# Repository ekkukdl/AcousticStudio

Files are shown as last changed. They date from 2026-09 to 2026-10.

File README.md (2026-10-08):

# Acoustic Control Studio

2026-10-08 T6 단면 클릭·드래그, 선택/전체 제어점 XYZ 이동, 비동기 궤적 이송과 최신 프레임 큐를 추가했습니다.
`구성 → 제어점`에서 이동 대상·단면·간격을 선택하며, 느린 계산에서는 이전 waypoint를 완료한 뒤 진행합니다.
[사용법·검증·현재 PC 성능](docs/ultraino_t6_result.md)을 확인하세요. 실제 터널 부양·이송 검증은 남아 있습니다.

현재 개발 저장소는 **[ekkukdl/AcousticStudio](https://github.com/ekkukdl/AcousticStudio)** 하나로 통합했습니다. 2026-10-07 기준 `AcousticStudio_ver2`의 코드, 구상도·PCB·Creo 자료 및 로컬 수정 내용을 반영했으며 두 저장소의 커밋 이력을 보존했습니다.

화면은 **보기 → UI → 클래식 / 모던**에서 선택합니다. 두 화면 모두 상단 **보드** 메뉴를 사용합니다. 설계 자료는 [구상도 시작 안내](구상도/START_HERE.md), 최신 32채널 PCB는 [제작 자료 안내](구상도/outputs/panel_8faces_32ch_R1/README.md)를 참고하세요. 통합 범위와 검증 기록은 [저장소 통합 기록](docs/repository_consolidation.md)에 있습니다.

Ultraino 기능 이식은 [작업 계획](docs/ultraino_migration_plan.md)을 기준으로 진행합니다. 현재 대상은 **Creo R2의 8면·8기판·기판당 32송신기, 총 256채널**이며 터널 축은 Z입니다. 기존 배열 좌표와 개발 환경을 재사용하는 범위 및 단계별 완료 조건을 정리했습니다. [입력·환경 점검 결과](docs/ultraino_migration_audit.json)는 현재 로컬 설치 상태의 기록입니다.

Acoustic Control Studio는 초음파 부상(Ultrasonic Levitation) 및 역장 제어(Acoustic Field Control) 연구를 위한 **통합 3D 시뮬레이션 및 하드웨어 제어 소프트웨어**입니다.
이 프로그램은 사용자가 직관적인 3D UI를 통해 센서 배열을 설계하고, 타겟의 위치를 조작하며, 실시간으로 위상(Phase)을 계산하여 하드웨어 보드(아두이노, FPGA 등)로 직접 전송할 수 있는 All-in-One 플랫폼을 제공합니다.

---

## 주요 기능 (Features)
- **3D 대화형 인터페이스 (Interactive 3D UI)**: PyVista 및 PySide6를 기반으로 한 3D 뷰어 제공.
- **다양한 배열 생성**: 터널형, 평면형, 반구형 등 복잡한 센서 배열(Array) 자동 생성 지원.
- **이기종 센서 하이브리드 지원**: 일반 10mm/16mm 초음파 센서와 고출력 랑주뱅(Langevin) 진동자의 혼합 시뮬레이션 지원.
- **실시간 위상 연산 (Real-time Phase Calculation)**: Twin Trap, Vortex Trap 등의 알고리즘을 적용하여 타겟 이동 시 위상을 즉각 재계산하고 색상으로 시각화.
- **하드웨어 연동 (USB Serial)**: 계산된 위상 데이터를 Byte 형식으로 변환하여 실시간으로 외부 제어 보드로 전송.

---

## 사전 설정 및 설치 가이드 (Prerequisites & Installation)

Creo 배열은 `구성 → 배열 형태 → Creo 8면 터널 · 8기판 × 32채널`을 선택하고 `배열 3D 렌더링 생성`으로 추가합니다. 기존 CAD 좌표를 읽으므로 일반 Grid/Spacing 값은 적용되지 않습니다. 위치·회전은 배열 전체에 적용되며, PCB 8개와 프레임 링 2개는 간략 형상으로 표시합니다. [구현 및 검증 기록](docs/ultraino_t1_result.md)을 참고하세요.

`음장 → 공통 음향 모델`에서 무지향, Ultraino sinc, 원형 피스톤을 선택합니다. 기본 개구는 미확정이며 CAD 외경에서 추정하지 않습니다. 방향성 모델에는 유효 음향 개구 반경이 필요하고, 음압은 미보정 상대값입니다. 설정을 바꾼 뒤 위상을 다시 계산하세요. [T2 결과 및 다음 작업](docs/ultraino_t2_result.md)에 데이터 계약과 검증 범위를 정리했습니다.

위상을 계산한 뒤 `음장 → 고정 위상 방사력·복원성 분석`에서 입자 물성, 중력, 평가 범위와 미분 간격을 입력합니다. 현재 송신을 고정한 XYZ 힘·퍼텐셜·복원 곡선과 전체 3×3 복원행렬을 확인하고 분석 JSON을 저장할 수 있습니다. 기본 물성은 예시이며 음압 미보정 상태의 힘은 N* 가정값입니다. 실제 중력 평형·부양 판정은 보류합니다. [T3 결과](docs/ultraino_t3_result.md)를 참고하세요.

다중 제어점을 활성화하고 `음장 → 다중 트랩 설계 (Kinoforms)`를 엽니다. 각 점에 Focus/Twin/Standing Wave, 상대 목표 음압 가중치와 세계 좌표 방향을 지정해 함께 계산합니다. 송신기 이득은 고정하고 위상만 조절하며, 반복 잔차·가중 음압 균일도를 확인한 뒤 `선택 트랩의 고정 위상 분석`으로 T3 복원 부호를 검사할 수 있습니다. `현재 배열에 위상 적용`과 `설계 JSON 저장`을 지원합니다. 음압 균일도는 부양 성공률이 아닙니다. [T4 사용·검증 및 T5 인계](docs/ultraino_t4_result.md)에 재현 방법을 정리했습니다.

`보드 → 채널 보정·맵 및 OFF 프레임…`에서 SW 채널별 위상 오프셋·고정 상대 이득·활성 상태와 후보 채널 맵을 편집하고 JSON/프로젝트로 저장합니다. 보정·맵·양자화·OFF는 실시간 송신과 궤적 내보내기에서 공통 사용합니다. 지원 프로파일의 OFF32와 위상0을 구분하며 Legacy OFF는 거절합니다. 실제 COM 없이 1채널/전체 OFF 프레임을 파일로 확인할 수 있습니다. [T5 사용·검증·T6 인계](docs/ultraino_t5_result.md)를 참고하세요. 실제 펌웨어·배선·파형 검증과 절대 음압 보정은 남아 있습니다.

상단 연산 모드에서 `PyTorch/CUDA: 선택 시 준비`를 선택하면 필요한 CUDA 패키지를 다운로드·확인한 뒤 그 모드를 적용합니다. `도구 → 라이브러리 관리자`의 `PyTorch/CUDA 사용` 체크도 같은 흐름입니다. 첫 준비는 수 GB 다운로드가 필요하며 이후 선택은 바로 전환합니다. 취소·실패는 이전 모드를 유지합니다. [선택 항목 적용 안내](docs/cuda_optional_selection.md)를 참고하세요. 다중 트랩은 복소 행렬 곱만 선택 엔진을 사용하며 작은 문제의 GPU 계산은 복사 비용 때문에 CPU보다 느릴 수 있습니다. [기존 원인·측정 기록](docs/multitrap_cuda_diagnosis.md)을 함께 확인할 수 있습니다.

현재 로컬 개발 환경은 Python 3.13.9이며, 확인한 인터프리터와 의존성은 [이식 계획의 환경 안내](docs/ultraino_migration_plan.md)에 있습니다. 기존 환경을 먼저 확인하고 재사용하세요. 기본 `py`가 선택하는 Python과 앱용 환경은 다를 수 있습니다. 필수 의존성 10개는 `requirements.txt`와 공통 설치 카탈로그에 일치하며, 확인한 버전은 [requirements-tested.txt](requirements-tested.txt)에 기록했습니다. T2는 이미 설치된 SciPy를 재사용했습니다. 아래 신규 설치 예시는 새 머신에 필요한 경우에 사용합니다.

### 1. Python 가상 환경 설정 (선택 사항이나 권장)
```bash
python -m venv venv
# Windows
venv\Scripts\activate
# Mac/Linux
source venv/bin/activate
```

### 2. 필수 라이브러리 설치
프로젝트 루트 폴더에 포함된 `requirements.txt`를 사용하여 의존성 패키지를 한 번에 설치합니다.
```bash
pip install -r requirements.txt
```
**[설치되는 주요 패키지]**
- `PySide6`: GUI 프레임워크
- `pyvista`, `pyvistaqt`, `vtk`: 3D 렌더링 및 기하학 연산 엔진
- `numpy`: 고속 배열 및 위상 수학 연산
- `pyserial`: 하드웨어(USB) 시리얼 통신 모듈

### 3. 프로그램 실행
모든 설치가 완료되었다면, 최상단 경로에서 아래 명령어를 통해 메인 창을 띄울 수 있습니다.
```bash
python main.py
```

---

## 디렉터리 구조 (Directory Structure)
- `src/acousticstudio/`: 애플리케이션의 핵심 소스 코드 (`app.py`, `app_backup.py` 등)
- `main.py`: 프로그램 실행 진입점 (Entry point)
- `docs/`: AI 에이전트 가이드라인 및 프로젝트 진행 상태(`project_status.txt`)가 기록된 문서 폴더
- `archive/temp_scripts/`: 개발 과정에서 생성된 임시 수정 스크립트(수동 코드 인젝션 파일) 모음 보관소
- `requirements.txt`: 의존성 패키지 목록

---

## 주의 사항 (Notes)
- **그래픽 드라이버**: 3D 렌더링 엔진인 VTK/PyVista를 사용하므로, 그래픽 드라이버(OpenGL 호환)가 정상적으로 설치된 환경에서 실행해야 튕김 현상이 발생하지 않습니다.
- **AI 작업 지침**: GPT/Codex를 포함한 코딩 에이전트는 [AGENTS.md](AGENTS.md)의 작업·백업·검증 규칙을 따릅니다. 기존 `GEMINI.md`도 이 공통 지침을 안내합니다. 스킬 점검 내역은 [docs/skill_audit.md](docs/skill_audit.md)에 있습니다.

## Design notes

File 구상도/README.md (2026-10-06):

# 부양 터널 구상도와 제작 자료

**현재 파일 위치와 최신 작업 안내는 [시작 안내](START_HERE.md)를 기준으로 찾으세요.** 아래 이동 기록은 2026-10-05 당시의 폴더 구조입니다. 2026-10-06 정리 후 PCB 자료는 `outputs/pcb/polygon_panels`, 모델 생성 기록은 `outputs/cad_generation`에 있습니다. 이전 경로와 실행 안내는 과거 기록으로 보존합니다.

기존 모델 폴더와 함께 설계 산출물 및 작업 스크립트를 이 폴더에서 관리합니다.

## 최신 제작분: 면당 32채널 PCB와 프레임

- [KiCad 10 회로도·PCB·제작 자료](outputs/panel_8faces_32ch_R1/README.md): 한 면에 4×8개, 8면 총 256채널. PCB 84×224×1.6 mm, 발진면 간격 210 mm.
- [진녹색 PCB 및 외부 프레임 Creo R2](outputs/panel_8faces_32ch_R1/mechanical/creo32_frame_R2/사용안내.md): 상하 팔각 링 2개, 외형 265×265×224 mm, 면 사이 촬영용 틈 유지.
- [프레임 포함 모델 ZIP](outputs/panel_8faces_32ch_R1/mechanical/creo32_frame_R2/Creo32_frame_R2_models.zip), [전체 제작 자료 ZIP](outputs/panel_8faces_32ch_R1/Design_R1_complete.zip).
- [기존 회로·제작 방식 분석](outputs/pcb_review_2026-10-06/), [KiCad 스킬 설치 기록](outputs/KiCad10_스킬_설치기록.md).

이전 16장 구성은 아래 폴더에 보존했습니다. 최신 설계의 검사 범위와 미확정 사항은 각 사용안내·검토 문서에 기록했습니다. `scratch/creo32_env` 등 실행 환경, PTC 설치 파일, Creo 실행 로그 및 KiCad 로컬 UI 설정은 Git에 포함하지 않습니다. Creo 세션의 PTC 런타임은 설치된 Creo에서 `prepare_creo32_r1.py`로 복사하며, 새 컴퓨터에서는 경로와 실행 환경을 맞춰야 합니다. 최상위 `제개설/8면_256채널_PCB_프레임_2026-10-06` 폴더는 로컬 정리본이며 이 저장소의 최신 산출물을 복사한 것입니다.

- `creo_tunnel/`: 정리된 Creo 모델. 단일 패널 초기안과 면당 두 패널의 최신안을 구분합니다.
- `outputs/`: KiCad 설계, Gerber 견적 ZIP, BOM·PnP, 개념 모델, 분석 결과, 원본 업체 템플릿.
- `scratch/`: 모델 생성·검증·견적 파일 생성 스크립트 및 중간 결과.
- `outputs/polygon_panels/pcba_8faces_16boards/DOILLABS/`: 최신 DOILLABS 양식의 BOM·PnP XLSX. 8면, 면당 두 기판, 총 16장 구성입니다.

이전 상위 자료조사 폴더의 `outputs/`와 `scratch/`는 2026-10-05에 이 위치로 이동했습니다. 내부 상대 디렉터리 구조와 파일 내용은 유지했습니다. 이동 전후 SHA-256 비교 기록은 `artifact_move_verification.json`에 있습니다.

`scratch/creo_cad_env/` 가상환경과 `scratch/pcba_artifact/node_modules/` 외부 라이브러리 연결은 로컬에 보존하며 Git에는 포함하지 않습니다. 다른 컴퓨터에서는 실행 환경을 별도로 준비해야 합니다. Windows 가상환경은 경로가 이동되면 실행기 내부 경로가 이전 위치를 가리킬 수 있으므로 필요 시 새 위치에서 재구성합니다.

상대 `outputs/`와 `scratch/` 경로를 사용하는 스크립트는 이 `구상도` 폴더를 작업 디렉터리로 사용합니다. 기존 스크립트에 남은 절대 경로, 이전 실행 기록의 경로, 일부 스크립트의 `AcousticStudio/` 참조는 생성 당시 기록입니다. 실행 전 해당 경로를 점검해야 합니다. 이번 작업은 파일 이동과 내용 보존을 검증했으며 Creo 재실행이나 전체 생성 스크립트의 재실행은 수행하지 않았습니다.

PCB 파일은 견적용 P0 설계입니다. 업체의 간격 경고, 부품 품번 및 실장 방향 확인은 아직 제조 승인 전에 필요합니다. 부양 성능은 실물 시험으로 검증해야 합니다.

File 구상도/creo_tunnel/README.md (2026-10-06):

# 초음파 부양 터널 Creo 모델

이 폴더는 이전 16채널 기판의 모델입니다. 현재 기준은 **8면·8기판·기판당 32송신기**인 [Creo R2 사용안내](../outputs/panel_8faces_32ch_R1/mechanical/creo32_frame_R2/사용안내.md)의 `tunnel8_32_r2.asm`입니다. 아래 v2의 16기판 모델을 현재 소프트웨어 배열 입력으로 사용하지 마세요.

Creo Parametric 9.0.12.0에서 저장한 모델입니다. 길이 단위는 mm(mmNs)입니다.

## 이전 v2 모델 열기

Creo 작업 폴더를 **`v2_dual_panel/native`**로 지정한 뒤 다음 조립품을 엽니다. ASM과 참조 PRT는 같은 폴더에 함께 보관해야 합니다.

- [8면 · 각 면에 PCB 두 장](v2_dual_panel/native/tunnel_8f_dual.asm)
- [6면 · 공통 패널 참조 구조](v2_dual_panel/native/tunnel_6f_v2.asm)
- [한 면의 PCB 두 장과 촬영 틈](v2_dual_panel/native/facepair_8f.asm)
- [이전 v2 모델 사용 안내](v2_dual_panel/사용안내.md)

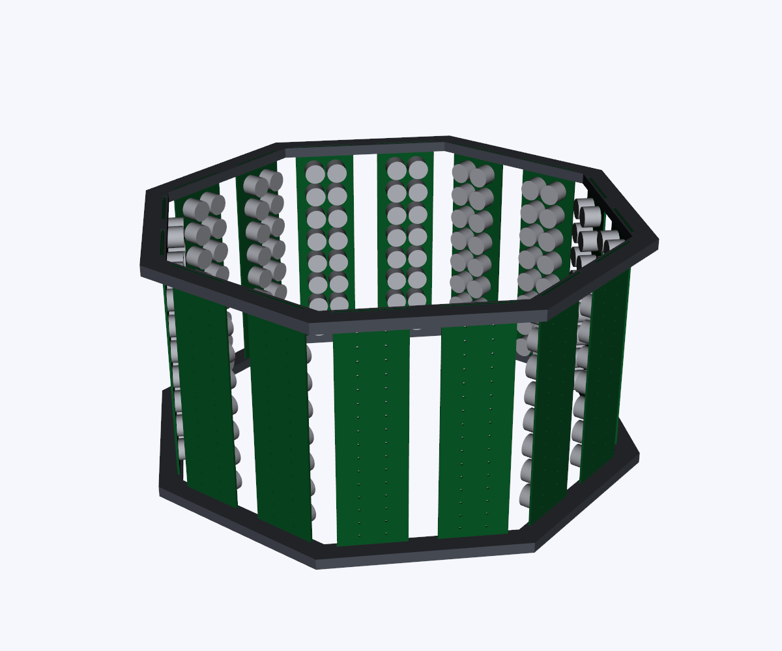
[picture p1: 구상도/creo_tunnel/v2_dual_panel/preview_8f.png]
이전 8면 v2 모델


## 버전 구분

| 폴더 | 6면 | 8면 |
|---|---|---|
| `v1_single_panel` | 면당 PCB 1장, 총 6장·96개 | 면당 PCB 1장, 총 8장·128개 |
| `v2_dual_panel` | 치수 유지, 공통 패널 ASM 재사용 | 면당 PCB 2장, 총 16장·256개, 중앙 촬영 틈 20 mm |

이전 6면 PCB는 60×180×1.6 mm, 8면 PCB는 48×180×1.6 mm입니다. 이전 v2의 8면은 각 면이 45° 간격인 정팔각형 배치이며, 마주 보는 방사면 간 거리는 300 mm, 전체 외곽은 약 355×355×180 mm입니다. 이전 두 조립품이 공유하는 네이티브 파일 종류는 총 10개입니다.

이전 v2의 8면은 `facepair_8f.asm` 하나를 8번 참조하고, 각 면은 `panel_8f.asm` 하나를 두 번 참조합니다. 동일한 PCB, 트랜스듀서 및 프레임 링도 공통 PRT를 참조합니다.

## 함께 보관한 자료

- `native`: 실제 Creo PRT/ASM. 재저장 시 붙는 `.1`, `.2` 등은 Creo 버전 번호입니다.
- `geometry`: 이전 v2 모델의 STEP 형상 및 배치·간섭 검사 기록.
- `pcb_geometry.json`: 기존 KiCad PCB에서 추출한 외곽 치수, 관통 구멍 및 트랜스듀서 좌표.
- `native_*report.json`: Creo 저장 및 새 세션에서 다시 열어 확인한 기록.
- `preview_*.png`: STEP 형상을 렌더링한 미리보기이며 Creo 화면 캡처는 아닙니다.
- `manifest.json`: 이 폴더에 정리된 파일의 SHA-256과 크기.

초기 모델의 STEP과 미리보기는 각 `6faces`, `8faces` 폴더에 있습니다. 기존 `구상도/ver1`~`ver4`는 별도의 기존 사용자 모델입니다.

## 검증 범위

원본과 정리된 파일의 SHA-256 일치, 네이티브 참조 파일의 완비 및 mm 치수 정보를 확인했습니다. 이전 v2 모델은 생성 당시 Creo 9에서 다시 열어 치수·반복 참조·배치 행렬·Fix 구속을 확인했고, 포함된 솔리드의 체적 간섭 검사도 수행했습니다.

PCB와 트랜스듀서는 가져온 솔리드이므로 스케치·돌출 피처 이력은 없습니다. 나사·브래킷·전자 부품·핀·배선은 생략되어 있습니다. 촬영 성능과 실제 부양 성능은 아직 검증하지 않았습니다.

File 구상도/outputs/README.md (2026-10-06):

# 결과물 안내

| 폴더 | 내용 |
|---|---|
| [pcb](pcb/README.md) | PCB 원본, Gerber·BOM·PnP, 초기 견적 |
| [cad_generation](cad_generation/) | 모델 생성 기록과 기존 배포 ZIP. 편집용 모델은 `../creo_tunnel`에 있습니다. |
| [budgets](budgets/) | 예산 계산 결과 |
| [vendor_templates](vendor_templates/) | DOILLABS 원본 양식 |
| [reference_analysis](reference_analysis/) | SonicSurface 참고 설계 분석 |
| [concepts](concepts/) | 초기 터널 개념도 |
| [docs](docs/) | KiCad 도구 설치 기록 |

전체 안내는 [START_HERE](../START_HERE.md)를 참고하세요.

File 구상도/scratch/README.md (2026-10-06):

# 작업 스크립트와 임시 자료

| 폴더 | 용도 |
|---|---|
| [creo_scripts](creo_scripts/) | 형상 추출, Creo 변환·패키지 생성·검증 |
| [pcba_scripts](pcba_scripts/) | 부품 입력 추출 및 업체 요청 패키지 생성·검증 |
| [pcba_inputs](pcba_inputs/) | PCBA 생성용 JSON·CSV 입력 |
| [pcba_artifact](pcba_artifact/) | Node 표 생성 스크립트, 미리보기와 로컬 의존성 |
| [vendor_research](vendor_research/) | 업체 조사 자료와 다운로드한 JS |
| [organization](organization/) | 이번 정리 스크립트와 이동 검증 기록 |
| [organization/history](organization/history/) | 이전 이동·복사·확인 스크립트 보존 |
| `creo_cad_env` | 로컬 Python 환경. 기존 경로 유지, Git 제외 |

실행 시 작업 디렉터리는 **상위 `구상도`**입니다. 예: `python scratch/pcba_scripts/extract_pcba_parts.py`.

생성 스크립트는 결과물을 덮어쓸 수 있고 Creo 자동화는 로컬 Creo와 생성 당시 임시 파일이 필요합니다. 이번 작업은 Python 문법과 경로 확인만 수행했으며 생성 파이프라인 전체를 재실행하지 않았습니다. `organization/history`는 과거 배치 기준의 기록으로 재실행용이 아닙니다. `reorganize_files.py`도 일회성 이동 기록이므로 다시 실행하지 마세요.

업체 제출 파일은 [PCB 안내](../outputs/pcb/README.md)에서 찾으세요. `vendor_research`의 JS는 참고 자료이며 앱 코드가 아닙니다.

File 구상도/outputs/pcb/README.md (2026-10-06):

# PCB 설계 및 업체 제출 자료

## 현재 8면 8기판 32채널 구성

현재 개발 기준은 한 기판 32채널, 같은 기판 8장, 총 256송신기입니다. [32채널 PCB R1 제작 자료](../panel_8faces_32ch_R1/README.md)와 [프레임 포함 Creo R2](../panel_8faces_32ch_R1/mechanical/creo32_frame_R2/사용안내.md)를 사용하세요. 아래 16채널 기판 16장의 업체 제출 자료는 이전 구성으로 보존한 것입니다.

## 이전 8면 16기판 요청

한 기판 16채널, 동일 기판 총 16장, 송신기 총 256개 구성입니다.

- [전체 납땜 요청 안내](polygon_panels/pcba_8faces_16boards/README_업로드_및_납땜요청.md)
- [DOILLABS 업로드 사용 안내](polygon_panels/pcba_8faces_16boards/DOILLABS/사용안내.txt)
- [업로드 BOM CSV](polygon_panels/pcba_8faces_16boards/DOILLABS/DOILLABS_BOM_8faces_16ch_UPLOAD.csv)
- [업로드 PnP CSV](polygon_panels/pcba_8faces_16boards/DOILLABS/DOILLABS_PnP_8faces_16ch_UPLOAD.csv)
- [업로드 BOM XLSX](polygon_panels/pcba_8faces_16boards/DOILLABS/DOILLABS_BOM_8faces_16ch_UPLOAD.xlsx)
- [업로드 PnP XLSX](polygon_panels/pcba_8faces_16boards/DOILLABS/DOILLABS_PnP_8faces_16ch_UPLOAD.xlsx)
- [8면용 Gerber ZIP](polygon_panels/pcba_8faces_16boards/panel_8faces_16ch_Gerber_P0_quote.zip)

DOILLABS에는 안내에 따라 `*_UPLOAD` 파일을 사용하세요. CSV와 같은 내용의 XLSX를 중복 제출하지 마세요. 접미사 없는 기존 XLSX와 기존 견적 ZIP은 이전 작성본으로 보존했으며 최신 UPLOAD 파일을 포함한다고 간주하지 마세요. 초음파 송신기 등 THT는 별도 수삽 작업으로 요청해야 합니다.

## KiCad 원본과 초기안

- [6면용 기판 원본](polygon_panels/panel_6faces_16ch/)
- [8면용 기판 원본](polygon_panels/panel_8faces_16ch/)
- [설계 설명](polygon_panels/설계설명_및_확인방법.md)
- [초기 Gerber ZIP](polygon_panels/gerber_quotes/)
- [초기 부품 견적](polygon_panels/부품견적_6면_8면.md)
- [초기 제조 및 추가 구매품 견적](polygon_panels/제작및추가부품견적_센서제외.md)

KiCad 프로젝트와 전용 심볼·풋프린트·3D 모델은 함께 보존했습니다. 기존 견적은 6면 6장 / 8면 8장 기준입니다. 현재 P0 자료의 간격 경고와 부품 방향 검토는 제조 승인 전에 필요합니다.

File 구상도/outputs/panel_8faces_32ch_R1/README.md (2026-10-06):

# 8면 터널용 32채널 PCB R1 — KiCad 10

기존 16채널 회로와 배선을 두 전기적 뱅크로 재사용해, 4열 × 8행의 트랜스듀서를 한 장에 배치한 새 설계입니다. 같은 PCB 8장으로 총 256채널을 구성합니다. 기존 설계 파일은 수정하지 않았습니다. 실제 PCB 발주·조립·구동은 수행하지 않았습니다.

## 파일 열기

`panel_8faces_32ch_R1.kicad_pro`를 KiCad 10에서 엽니다. 회로도와 PCB, 프로젝트 로컬 심벌/풋프린트 및 모델이 함께 들어 있습니다. 회로도는 620 × 460 mm 사용자 용지의 단일 시트입니다.

## 이번 시제품의 치수

| 항목 | R1 값 | 의미 |
|---|---:|---|
| PCB | 84 × 224 × 1.6 mm | 2층, 면마다 1장 |
| 발진면 맞은편 거리 | 210 mm | 기존 300 mm에서 축소한 시작점 |
| PCB 앞면의 중심까지 거리 | 117.5 mm | 발진면 거리 + 가정한 소자 높이 12.5 mm |
| 트랜스듀서 | 4 × 8, 지름 16 mm | 기존 풋프린트 사용, 정확한 구매품 확인 필요 |
| 열 중심 간격 | 18 / 22 / 18 mm | 두 기존 배선 셀 사이에 4 mm를 더 확보 |
| 행 중심 간격 | 20 mm | 기존과 동일 |
| 위·아래 고정 여백 | 각각 22 mm | 부품·배선·동박 채움 없는 영역 |
| 고정 구멍 | 4개, 지름 3.2 mm NPTH | (6,11), (78,11), (6,213), (78,213) mm |
| 인접 PCB 앞면 모서리 거리 | 약 12.325 mm | 광학 유효 개구 폭이나 시야각을 뜻하지 않음 |

기판 내부 슬롯은 없습니다. 기판 사이 틈을 남기는 정팔각형 터널 배치이며 외부 카메라와 회전 프레임 자체는 이번 설계 범위 밖입니다. 물체 전체가 보이는 조건은 유지해야 하지만 물체 크기와 촬영 위치가 없어 아직 증명되지 않았습니다.

200 mm가 절대 기준은 아니므로, 기존 셀 배선 유지와 틈 확보를 위해 210 mm를 선택했습니다. 같은 84 mm PCB를 발진면 거리 200 mm로 배치하면 앞면 모서리 거리는 약 8.498 mm로 줄어듭니다. 두 경우 모두 소자 외피는 단순 모델상 충돌하지 않지만 카메라 시야·음향 부상 성능은 별도 검증이 필요합니다. 기판 뒤 부품, 케이블, 프레임은 틈을 더 가릴 수 있습니다.

`parameters.json`은 현재 치수 기록입니다. 생성 스크립트는 보드 폭·길이와 발진면 거리를 조정할 수 있으나 열·행 간격, 소자 높이, 고정 여백 변경을 임의로 자동 배선하지 않습니다. 변경 후 네이티브 파일·간섭·ERC/DRC·제조 파일을 다시 검증해야 합니다. JSON 수치만 바꿔 기존 Gerber를 그대로 사용할 수 없습니다.

## 전기 구성과 연결

32채널을 16채널 A/B 뱅크로 나눕니다. 뱅크 사이에서 PCB 내부로 연결된 공통 전원망은 GND뿐입니다. +5V_A/B, DRV_VDD_A/B, SHIFT/LATCH/ARM_A/B는 각각 외부에서 공급합니다. 같은 공급원이나 클록을 쓰려면 외부 분배가 필요합니다. 한쪽 헤더만 연결하면 다른 뱅크가 자동 동작하지 않습니다.

| 핀 | J1: BANK A 신호 | J2: BANK B 신호 |
|---:|---|---|
|1|GND|GND|
|2|+5V_A|+5V_B|
|3|DATA_A0|DATA_B0|
|4|GND|GND|
|5|DATA_A1|DATA_B1|
|6|GND|GND|
|7|SHIFT_PIN_A|SHIFT_PIN_B|
|8|LATCH_PIN_A|LATCH_PIN_B|
|9|ARM_A|ARM_B|
|10|GND|GND|

J3(A), J4(B) 전원 헤더는 1=DRV_VDD, 2=GND, 3=+5V입니다. 실크와 패드 번호를 기준으로 확인하고 커넥터 뒷면 시점의 좌우를 추측하지 마세요. +5V는 5 V 로직 공급이며 TC4427A의 드라이버 전원 허용 범위는 4.5–18 V입니다. 실제 트랜스듀서의 연속 구동 정격 확인 전 드라이버 전압을 확정하지 않습니다.

ARM 기본 풀다운 → MMBT3904 OFF → 74HCT595 /OE 풀업으로 출력 비활성화합니다. 입력 풀다운으로 TC4427A 입력의 부유를 방지합니다. 전원 안정 후 ARM 비활성 상태에서 4개의 데이터 라인에 값을 시프트하고 래치한 다음 ARM을 활성화하는 순서를 사용합니다. 외부 FPGA와 헤더 배선은 이번에 변경하지 않았습니다.

T1…T32는 행 우선 순서입니다. QA…QH 출력 기준 `channel_map.csv`와 전체 256개 위치 `array_positions_256.json`을 제공합니다. `physical_to_software_channel_map.json`은 문서화한 DATA 순서에 대응하는 후보이며 FPGA의 실제 시프트 비트 방향과 헤더 배선을 확인하기 전 기존 프로그램에 바로 적용하지 않습니다.

## 제작·조립 자료

- `Gerber_R1_PCB_only.zip`: 동박·마스크·실크·페이스트·외곽, PTH/NPTH 드릴 및 Gerber job. PCB 1장 패턴이며 8장 주문 수량은 별도 지정합니다.
- `BOM_ALL.csv`, `BOM_SMT.csv`, `BOM_THT.csv`: 1장 및 8장 수량, 후보 MPN. 1장당 SMT 110개와 THT 38개입니다. M3 고정 나사·프레임·케이블은 포함하지 않습니다.
- `PnP_SMT_KiCad.csv`: KiCad 원본 좌표, mm, Bottom, X 양수/Y 음수. 임의 미러 변환을 하지 않았습니다. 업체의 바닥면 좌표 규약과 반드시 맞춰야 합니다.
- `THT_Placement.csv`: 트랜스듀서·헤더·전해콘덴서 수동 조립 위치. TX 패드1=출력/패드2=GND, 전해콘덴서 패드1=양극입니다.
- `mechanical/panel_board_only.step`: 실제 PCB 외곽·고정 구멍의 STEP. 부품 및 외부 프레임 미포함.
- `mechanical/tunnel_envelope.scad`: 8면 PCB/소자 외피의 치수 모델. 고정 구조 설계용 완성 프레임이 아닙니다.
- `geometry_preview.png`, `assembly_preview.png`, `pcb_top.png`, `pcb_bottom.png`, `schematic_preview.png`: 배치·실제 회로도·배선 미리보기.

PCB 제안 사양은 FR-4, 2층, 1.6 mm, 1 oz 동박이며 제작업체의 실제 공정 사양을 확인해야 합니다. 업체 패널라이징, 리플로우 캐리어, 스텐실 여백, 부품 대체 선정은 이번 패키지에 포함하지 않습니다. THT 트랜스듀서는 안쪽 F면, 구동 부품은 바깥쪽 B면에 배치합니다.

## 검증과 남은 사항

KiCad 10.0.6 ERC 0, DRC 위반 0, 미연결 0, 회로도/PCB 불일치 0. 별도 검증에서 전기 패드 468개(연결 432개/명시 NC 36개), 32개 출력 경로, 256채널 맵, SMT 좌표와 고정 여백을 확인했습니다. 원본 PCB의 SHA-256도 유지되었습니다. GND 비아 92개를 추가했습니다.

기존 프로젝트의 5개 DRC ignore 설정과 ERC ignore 설정은 유지되며 검증 범위는 `DESIGN_REVIEW.md`에 기록했습니다. 제조업체 DFM, 실제 전류·온도·신호 파형·음향 부상과 전체 물체 촬영은 검증되지 않았습니다. 자동 EMC 검토의 귀환 경로 및 외부 케이블 경고가 남아 있어 측정과 필요시 배선 수정이 필요합니다. 자세한 판단과 근거는 `DESIGN_REVIEW.md`, 기계 판정은 `geometry_summary.json`, 원시 검사 결과는 `analysis/`에 있습니다.

## 재생성

프로젝트 루트에서 `구상도/scratch/build_panel32_r1.py`와 `stitch_panel32_r1.py`, `verify_panel32_r1.py`를 KiCad 내장 Python으로 실행합니다. `export_panel32_r1.py`, `render_panel32_r1.py`, `package_panel32_r1.py`는 시스템 Python을 사용합니다. 검증은 ERC/DRC와 XML netlist 내보내기 뒤 수행합니다. 렌더에는 로컬 resvg-py/Pillow, 치수 미리보기에는 numpy/matplotlib이 필요합니다. 생성은 기존 16채널 소스 셀을 읽으므로 소스 폴더가 필요하며 새 설계를 편집한 뒤 생성 스크립트를 다시 실행하면 R1 편집 내용이 덮어써집니다.

## 색상 및 외부 프레임 포함 Creo 모델 R2

[전체 조립체](mechanical/creo32_frame_R2/native/tunnel8_32_r2.asm)는 진녹색 PCB 8장과 회색 상하 팔각 링 2개를 포함합니다. 전체 외형 265×265×224 mm, 기존 PCB 고정 구멍에 맞춘 M3 체결 구멍 및 촬영용 면간 틈을 유지했습니다. [Creo R2 사용안내](mechanical/creo32_frame_R2/사용안내.md)에 치수·파일·검증 범위가 있으며, [모델 ZIP](mechanical/creo32_frame_R2/Creo32_frame_R2_models.zip)에 모든 참조 단품을 포함했습니다. 기판 조립체는 `panel32_r2.asm`, 기판 단품은 `pcb32_r2.prt`, 링 단품은 `ring8_32_r2.prt`입니다. 이전 R1 모델은 보존했습니다.

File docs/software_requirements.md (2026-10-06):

# Fixtureless 360° inspection software roadmap

## Current implementation scope as of 2026-10-07

For the current Ultraino migration, follow [the migration plan](ultraino_migration_plan.md): Creo R2, eight faces, one 32-transducer PCB per face, eight PCBs and 256 channels, with the tunnel along Z. The immediate workflow is levitation, axial transport and holding at the inspection position. The camera, inspection and orientation functions below remain a separate longer-term roadmap. Reuse the existing board profiles and calibration mapping API rather than implementing a second transport layer.

## Goal and current boundary

The target system described in `설계문제정의보고서.hwp` is an inspection
workflow, not only an acoustic-field viewer:

`levitate / orient → verify stability → capture images → reconstruct and compare → decide pass/fail`

AcousticStudio currently covers array design, phase calculation, field display,
trajectory generation, relative trap-stiffness diagnosis, k-Wave 2D analysis,
and phase-frame transmission.  A displayed stability score is a model-relative
score, not a measured levitation success rate.

## Implemented in this update

### Board profile and transport layer

`acousticstudio.hardware` now owns the board protocol rather than allowing UI
code to construct raw packets.  The selectable profiles are:

| Profile | Frame / transport | Reference inspected |
| --- | --- | --- |
| Legacy Phase32 | `0xFE + N×phase(0..31) + 0xFD` | Existing AcousticStudio behavior |
| Ultraino SimpleFPGA 256 | `0xFE + 256×phase + 0xFD`, 230400 baud | `Ultraino/.../SimpleFPGA.java` |
| SonicSurface FPGA 256 (direct) | `0xFE + 256×phase + 0xFD`, 230400 baud | `SonicSurface/.../TestHoloConnection4.ino` |
| SonicSurface FPGA 256 (board tags) | `0xFE, 0xC0, 128 phases, 0xC1, 128 phases, 0xFD` | `SonicSurface/.../CommandSenderESP32.ino` |
| SonicSurface ESP32 CommandSender | `phases=<256 comma-separated values>,\n`, 230400 baud | `SonicSurface/.../CommandSenderESP32.ino` |

Fixed 256-channel profiles reject partial arrays. Phase values are finite
radians, wrapped before 32-step quantisation; code `32` is never emitted as a
phase because the SonicSurface firmware uses it as an off value. The selected
profile is stored in project JSON. A validated physical-frame-index to
software-channel mapping API is included for a future calibration result.

These are software framing checks only. The selected profile must match the
firmware actually flashed on the connected board. No physical board acceptance,
channel order, or levitation result has been verified here.

## Remaining implementation backlog

### P0 — required for a credible inspection demonstrator

1. **Field mapping and calibration**: control a microphone/receiver scan,
   estimate channel amplitude and phase errors, review the map, store its
   provenance, and apply it through the channel-map/calibration layer.
2. **Vision closed loop**: camera acquisition, intrinsic/extrinsic calibration,
   part pose and angle estimation, bounded controller, settle-time criterion,
   then deterministic image capture.
3. **Safety state machine**: explicit idle/armed/levitating/moving/settling/
   capturing/fault states; emergency output-off; communication timeout;
   object-loss and camera-loss handling. Never continue to capture after a
   failed state transition.
4. **Board validation**: fake-serial protocol tests plus a physical test sheet
   for boot version, channel map, 32-step convention, frame commit, maximum
   sustainable update rate, and disconnect behavior.

### P1 — inspection-system functions

1. **Part recipe**: versioned CAD/mesh, mass/material, allowed orientation,
   array geometry, calibration IDs, camera setup, angle plan and tolerances.
2. **Acquisition and traceability**: per-part ID, timestamped raw images,
   command/pose/quality log, calibration versions and repeatable export.
3. **Geometry inspection**: image registration, point cloud/mesh reconstruction,
   CAD registration, deviation map and tolerance decision.
4. **Appearance inspection**: labelled image dataset, inference interface,
   defect location/severity, human review and combined geometry/appearance
   pass-fail report.

### P2 — higher-fidelity design analysis

1. Model mass, inertia, geometry and orientation-dependent force/torque; do
   not infer six-degree-of-freedom stability from a scalar stiffness score.
2. Validate k-Wave grid/time convergence and compare against measured fields.
   The present 2D result (`p_max` and final transient sample) is not by itself a
   3D steady-state validation.
3. Add robust phase optimisation with measured channel errors and phase
   quantisation in the objective, then compare a deterministic small case among
   CPU/native/GPU implementations.

## Acceptance milestones

| Milestone | Evidence required |
| --- | --- |
| Board protocol ready | Unit tests plus physical captured frame/firmware version/channel mapping record |
| Controlled rotation | Pose error, settle time and repeatability across a defined number of cycles |
| Calibrated field | Measured versus predicted amplitude/phase map and applied correction version |
| Inspection result | Raw images, reconstruction/CAD deviation, AI result, final decision and recipe ID |

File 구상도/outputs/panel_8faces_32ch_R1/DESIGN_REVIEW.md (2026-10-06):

# R1 설계 검토 — KiCad 10.0.6 / 2026-10-06

## Overview / 판정

**새 네이티브 회로도·배선된 PCB·제작 출력의 시제품 설계가 완료되었습니다. 성능 및 생산 승인까지 검증한 설계는 아닙니다.** 원본 16채널 셀을 두 개 합쳐 32채널 한 장으로 만들었습니다. 외부 전원·FPGA·카메라·프레임은 별도 구성입니다.

## Critical Findings / 우선 확인

| 항목 | 판단·신뢰도 | 근거 및 영향 |
|---|---|---|
| FPGA 시프트 순서·헤더 분배 | 미확인 | 기존 펌웨어를 수정하지 않음. 맵은 QA…QH와 문서상 DATA 순서만 보장 |
| 트랜스듀서 정확한 제조사·연속 전압·정전용량 | 미확인 | D16/P10 기존 풋프린트만 유지. 전압과 열·전류 예산 확정 불가 |
| 물체 전체 촬영 | 미확인 | 물체 크기·카메라 위치 미정. 12.325 mm 기판 모서리 거리는 촬영 성립 증명이 아님 |
| 출력 귀환 경로·외부 케이블 EMC | heuristic / 중간 이하 | 자동 EMC가 92개 항목을 보고. 제조 연결 오류와 분리하여 파형·방사 실측 필요 |
| 전원 공급/커넥터 전류 용량 | inference-only | 동시 256채널 전류 미정. 보호·외부 분배·전압강하를 시스템에서 확인 |

## Previous Review Delta

기존 면당 16채널 PCB 2장/총16장에서 면당32채널 PCB1장/총8장으로 변경했습니다. 중앙 기판 슬롯을 제거하고 인접 면 틈은 유지했습니다. 기존 열18/행20 mm 간격을 유지하면서 두 셀 사이 열만22 mm로 조정했습니다. 발진면 거리300→210 mm, PCB84×224 mm, 고정 여백22 mm, GND 비아92개 추가. IC 구매 후보 표기를 Nexperia 74HCT595D,118로 통일했습니다. `delta_from_16ch.json`은 초기 분석 대비 자료이며 이후 GND 보강은 `stitching.json`에 별도 기록됩니다. 이전 업체의 0.002 mm 간격 지적은 원래 오류 좌표가 없어 해결을 단정하지 않습니다.

## Component Summary

74HCT595 4개, TC4427A16개, MMBT3904 2개, 저항50개, MLCC38개, 전해2개, 헤더4개, TX32개 = 전기부품148개/장. 고정홀4개 별도. SMT110/THT38. MPN은 BOM 후보이며 확정 구매 지시가 아닙니다. 제조사 미정 TX/헤더와 일부 배급사 번호가 없는 부품은 구매 확인이 필요합니다.

## Power Tree / Power Analysis

외부 +5V_A/B → 각 74HCT595 2개, OE/ARM 회로, 100 nF 2개 +10 µF 1개/뱅크.
외부 DRV_VDD_A/B → 각 TC4427A8개, 100 nF8개 +1 µF8개 +220 µF1개/뱅크.
GND는 두 뱅크 공통. 레귤레이터·전원 역접 보호·입력 퓨즈·전압감지 회로는 없음.
74HCT595은5 V 로직, TC4427A4.5–18 V 전원 범위(제조사 PDF p1), TTL 입력. TC4427A는 트랜스듀서 한쪽을 구동하는 비반전 듀얼 출력이며 브리지 구동이 아님. 1.5 A 표기는 드라이버의 피크 능력이며 연속 PCB 전류 정격으로 해석하지 않습니다. 용량성 전류/동적 소비는 주파수·부하 정전용량·전압·파형과 손실에 따라 달라 실측 예산이 필요합니다. 동박1oz는 제안값이며 실측 전류/허용 온도상승으로 재평가해야 합니다.

## Analyzer Verification / 핀 근거

별도 `verification.json` 검사는 원시 PCB 패드468개와 새 XML 네트리스트의 모든 핀을 대조하여 일치 확인(raw-file verified / 높음). 명시 NC36개와 기계NPTH4개는 구분했습니다. QA…QH→IN→TC4427A→OUT→TX32개 전부 검증했습니다.

| 부품 | 제조사 PDF / 페이지 | 검증 상태 |
|---|---|---|
| U1–U4 / 74HCT595D | Nexperia 74HC_HCT595, p5 핀 설명, p2 SO16 | datasheet-verified / 높음: 16VCC,8GND,14DATA,11SHIFT,12LATCH,13/OE,10/MR; 출력15,1…7 |
| U5–U20 / TC4427A | Microchip DS20001423, p8 핀 기능 | datasheet-verified / 높음: 2INA,3GND,4INB,5OUTB,6VDD,7OUTA,1/8NC |
| Q1–Q2 / MMBT3904 | Nexperia MMBT3904, p1 핀 표 | datasheet-verified / 높음: 1B,2E,3C |
| R1–R50,C1–C40 | 원시 패드/넷 대조; 후보 구매품 PDF 전수 검증 미실시 | raw-file verified / 높음; 제조사 공차·전압·패키지 전수는 미확인 |
| J1–J4 | 원시 번호/네트 대조 | raw-file verified / 높음; 구매 커넥터 방향·길이 미확인 |
| T1–T32 | 기존 D16/P10 모델 및 원시 패드 대조 | raw-file verified / 높음; 실제 송신기 데이터시트 미확인 |
| H1–H4 | PCB NPTH 지름3.2 mm | raw-file verified / 높음; 고정 하드웨어는 범위 밖 |

공식 PDF는 `datasheets/`에 보관했습니다. 구조화된 데이터시트 extraction 검증은 수행하지 않았으며 제조사 표를 직접 대조했습니다. 전체 부품의 제조사 데이터시트 검증이 완료되었다고 주장하지 않습니다.

## Signal Analysis Review

각 뱅크별 33 Ω 클록/래치 직렬 저항과 입력100 kΩ 풀다운을 유지했습니다. DATA0/1 각각8비트, SHIFT/LATCH/OE 공유인 두595 구성입니다. QA와 마지막에 시프트한 비트의 관계는 FPGA 구현에서 확인해야 합니다. ARM=LOW에서 Q OFF, OE HIGH,595출력고임피던스; 드라이버입력 풀다운으로 출력LOW가 의도됩니다(raw topology verified; 기동 과도파형 미측정). 출력 핀 접속만으로 FPGA 타이밍이나 음향 위상 보정까지 검증되지는 않습니다.

## PCB Layout Analysis

2층,84×224×1.6 mm. 트랙1408개, 비아206개(기존셀114+GND보강92). TX는 F면, 구동부 B면. 고정구간 y0–22 및202–224 mm는 전기 패드/배선 없는 것 확인. GND 두 면 채움, 뱅크 전원은 분리. 통합PCB 전체 시야·후면 하드웨어 간섭은 미검증.

## Thermal Analysis

`analyze_thermal.py`를 실행했으나 지원되는 발열부품/손실 데이터가 없어 분석이 SKIPPED되었습니다. TC4427A와 TX의 실제 손실·온도, 256채널 동시 동작 조건을 계산/측정하지 않았습니다. 열 안전 판정 없음.

## EMC / Cross-Domain Analysis

`analyze_emc.py` 재실행 92개: {'error': 26, 'warning': 53, 'info': 13}. 점수34/100은 해당 도구의 휴리스틱이며 인증 점수나 제조 합격 기준이 아닙니다. 출력 OUT의 참조면 공백과 층전환 귀환 경로, 드라이버 디커플링 거리, 외부커넥터 보호/필터를 주로 지적합니다. GND 비아를 추가한 후 cross_analysis의 접지 비아 밀도 경고는0개가 되었습니다. 다른 EMC 경고를 해결한 것으로 표시하지 않습니다. 짧은 드라이버-출력선도 빠른 에지가 있으므로 근거 없이 오탐 처리하지 않았습니다. 외부 케이블 길이, 스코프 입력/출력 파형, 링잉/그라운드바운스와 동시 스위칭을 확인하여 재배선 필요성을 판단합니다.

## Component Lifecycle

`lifecycle_audit.py --onlylcsc` 실행10개 후보 모두unknown. 이 모드는 수명상태를 확인할 수 없다는 도구 설명이 있어 공급/단종 상태로 해석하지 않습니다. 공식 제조사 생산 상태 및 실제 재고는 확인되지 않았습니다.

## Manufacturing / DFM / Testability

KiCad ERC0/DRC0/미연결0/패리티0. 9개 Gerber 및 독립 PTH/NPTH 드릴을 새 보드에서 출력했습니다. 정렬 경고는 동박영역 높이180 mm와 외곽224 mm의 의도된44 mm 차이이며 동일 좌표 원점을 유지합니다. 위·아래는 동박을 의도적으로 비웠으므로 레이어의 occupied bounding box가 같을 필요는 없습니다. Drill/outline/패드의 좌표 기준을 실제PCB 출력과 대조했습니다. SMT좌표110개를 manifest와 대조했으며 임의 bottom미러 변환 없음.

기존 커스텀 풋프린트에는 일부 courtyard가 없습니다. 업체 DFM과 조립방향·TX 극성·기구 높이 확인이 필요합니다. 전용 테스트 포인트/공장검사 지그는 추가하지 않았습니다. 헤더에서 전원·ARM·클록·데이터 확인, ARM off에서 전류 확인, 채널별 순차 활성화, 전체 동시 구동을 단계적으로 검증하는 것이 적절합니다(inference-only).

## False Positives / Reviewer Overrides

- KO-001 고정홀 keepout 오류4개: NPTH이며 KiCad rule-area가 패드/기계홀을 허용하고 트랙·비아·동박 채움만 금지합니다. 실제DRC0과 전기패드 부재 확인으로 오탐 판정(raw-file verified). 구멍을 전기적 접지 패드로 변경하지 않았습니다.
- GR-002 레이어 높이44 mm 차이: 고정용 무동박 영역 때문. 레이어 자동 bounding-box 비교에 따른 정렬 오탐이며 Gerber 원점이 다른 증거가 아님.
- 자동 lifecycle unknown 및 디커플링 거리 경고를 생산/전기 실패로 단정하지 않음. EMC 출력 참조면 경고는 남은 검토사항으로 보존.

## Not Performed / Review Limits

실행: KiCad ERC/DRC/패리티, XML netlist전수대조, analyze_schematic.py, analyze_pcb.py --full, analyze_gerbers.py, cross_analysis.py, analyze_emc.py, analyze_thermal.py(실행 후SKIPPED), lifecycle_audit.py(unknown), diff_analysis.py(16ch 초기분석 대비). 분석 결과는 `analysis/`에 보관.

미실행: SPICE(ngspice/상용엔진 설치없음, TX모델없음), 발주업체 DFM/패널화, FPGA 빌드·비트순서/배선 통합시험, 전체 제조사 부품 PDF확인, 열손실 계산/온도측정, 전류·EMI실측, 음향장/부상 실험, 카메라 광학 검증, 외부 프레임과 케이블 3D간섭 검사.

프로젝트 DRC ignore 유지: footprint_filters_mismatch, footprint_type_mismatch, missing_courtyard, track_not_centered_on_via, tuning_profile_track_geometries. ERC ignored_checks는 `ERC.json` 원문에 기록. 제외된 검사를 포함한 무조건 오류0 또는 양산 승인으로 해석하지 않습니다. 실제 위반을 항목별로 숨기는 DRC exclusions는 비어 있습니다.

## Final Verdict / trust_summary

원시파일·제조사 핵심IC 핀 연결: 신뢰 높음. 후보부품 완전성·열·EMC·FPGA 통합·음향/광학: 미확인 또는 휴리스틱. **KiCad 10에서 편집·검토할 수 있는 새 시제품 제작자료를 제공하며, 실물 성능·제조업체 승인 완료는 주장하지 않습니다.**

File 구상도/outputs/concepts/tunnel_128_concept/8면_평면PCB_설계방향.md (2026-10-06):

# 8면 평면 PCB 배열 설계 방향

2026-10-04. 사용자 제시 이미지처럼 평면 패널을 다각형 프레임 둘레에 장착하는 구조로 설계 방향을 변경한다. 기존 곡면 FPCB 모델은 이전 검토안으로 보관한다.

## 적용 조건

기존 요청은 16mm 송신기, 128개 독립 채널, Langevin 제외이다. 새 이미지에는 256채널이 표시되어 있으므로 사용자 확인 전에는 기존 128채널 조건을 유지한다. 이미지 치수는 제작 도면으로 확정하지 않는다.

| 항목 | 현재 설계 제안 | 이미지의 256채널 구성 |
|---|---:|---:|
| 패널 수 | 8 | 8 |
| 패널당 송신기 | 16 (2열 × 8개) | 32 (2열 × 16개) |
| 전체 송신기 | 128 | 256 |
| 패널당 8출력 시프트 레지스터 | 2 | 4 |
| 패널당 듀얼 드라이버 | 8 | 16 |
| 전체 시프트 레지스터 | 16 | 32 |
| 전체 듀얼 드라이버 | 64 | 128 |

각 송신기는 드라이버 출력 한 개와 GND로 구동하는 단일 출력 방식 기준이다. 브리지 구동을 채택하면 드라이버 개수가 달라진다. 드라이버는 MIC4127 또는 TC4427A를 검토하되 전압 정격과 실제 구매 부품에 맞춰 회로를 확정한다.

## 기판 및 조립 구조

우선 검토안은 동일한 양면 실장 평면 FR-4 PCB 8장이다. 안쪽 면에 송신기를 관통형으로 납땜하고 바깥쪽 면에 레지스터, 드라이버, 커패시터와 커넥터를 배치한다. 앞/뒤 동박이 있는 양면 기판과 앞/뒤로 부품을 장착하는 양면 실장은 다른 개념이다. 필요한 동박 층수는 배선 및 접지 품질을 검토한 뒤 결정한다.

이미지의 단면처럼 송신기 PCB와 드라이버 PCB를 두 장으로 분리할 수도 있다. 이 경우 패널 내부에 16개 독립 출력과 GND를 연결하는 커넥터/배선 및 스페이서가 추가된다. 정비나 부품 공간을 위해 필요한 경우에 선택한다. 통합 보드는 부품 후면 배선과 송신기 핀 납땜 자리의 간섭을 확인해야 한다.

프레임은 송신기의 하중과 패널 고정을 담당한다. 방사면 앞을 가리는 브래킷은 피하고, 케이블과 전원 커넥터는 바깥쪽에서 접근하게 한다. 각 패널의 장착 각도와 위치는 음향 모델의 좌표와 일치해야 한다.

## 치수 검토

16mm 몸체를 16개 길이 방향으로 배치하면 간격 없이도 256mm가 필요하다. 따라서 이미지의 2×16 배열과 약 200mm 높이는 동시에 만족할 수 없다. 중심 간격 20mm를 가정하면 송신기 부분 길이는 `(16-1)*20+16 = 316mm`이며, 기판 끝 여유 및 커넥터는 추가된다.

128채널의 2×8 배열에서는 같은 중심 간격일 때 송신기 부분 길이가 `(8-1)*20+16 = 156mm`다. 가로 중심 간격 18mm를 가정하면 송신기 부분 폭은 `18+16 = 34mm`다. 기판 40×180mm는 배치 검토용 후보로 삼을 수 있으나, 고정홀·전자부품·커넥터를 넣은 결과에 따라 확대해야 한다. 확정 제작 치수가 아니다.

방사면 기준으로 마주 보는 면 사이가 150mm인 정팔각형을 예시로 잡으면 아포팀은 75mm, 한 변 길이는 `2*75*tan(22.5°) = 약 62.13mm`다. 패널 폭이 이보다 좁으면 패널 사이에는 개방 구간이 생긴다. 실제 기판 위치는 방사면보다 송신기 몸체 높이만큼 바깥쪽이다. 이미지의 외곽 300mm는 이 계산에서 자동으로 나오는 값이 아니며 프레임 단면과 장착 구조로 별도 확정해야 한다.

평면 패널의 모든 송신기는 해당 패널에 수직으로 방사한다. 중앙축에서 벗어난 두 열의 송신기를 개별적으로 중앙에 기울인 배치는 아니다. 시뮬레이션에도 각각의 실제 방향을 넣어야 한다.

## 전기 연결 제안

PC → FPGA → 8개 패널의 레지스터 → 드라이버 → 송신기로 연결한다. FPGA는 연속 40kHz 타이밍을 생성하고 PC는 목표 위상을 계산/전송한다.

FPGA 3.3V 신호를 5V 레지스터에 입력하는 경우 74HC595의 입력 임계값을 무조건 만족한다고 가정하지 않는다. 74HCT595 또는 명확한 레벨 변환 회로를 우선 검토한다. HCT595 2개에 각각 독립 데이터를 공급하는 안이라면 패널당 DATA 2줄, 공통 SHIFT/LATCH 클록, GND 및 필요한 전원 배선을 구성한다. 기존 256채널 펌웨어의 채널 매핑을 새 128채널 배열에 맞게 수정해야 한다.

구동 전원과 5V 논리 전원은 구분한다. 전원 분배부에서 각 패널로 공급하고 모든 GND는 연결한다. 패널마다 드라이버 근처의 로컬 디커플링과 벌크 커패시터를 둔다. FPGA 신호선은 전원과 함께 긴 무계획 직렬 연결로 이어붙이지 않고 클록 부하·배선 길이·접지 귀환 경로를 검토한다.

송신기의 상대 음향 극성을 조립 전에 확인하고 표시한다. 뒤집힌 채널은 배선을 수정하거나 위상에 180° 보정한다. 전원을 켤 때 출력이 의도하지 않게 켜지지 않도록 초기화와 출력 비활성 상태도 설계한다.

## 제작 파일로 넘어가기 전에 필요한 작업

채널 수 및 프레임 치수 확정 → 실물 송신기 풋프린트 확인 → 16채널 패널 회로도 → 기판 배치/배선 → ERC/DRC → 소규모 시제품 파형·발열·위상 검증 → 8패널 음장 및 부양 검증 순서로 진행한다.

이 문서는 새 구조의 설계 조건 정리이며, KiCad 원본이나 제조용 Gerber가 아니다. 기존 SonicSurface 동박 연결 검증을 새 구조의 전기/음향 검증 완료로 해석하지 않는다.

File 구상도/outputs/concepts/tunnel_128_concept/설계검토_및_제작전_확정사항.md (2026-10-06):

# 4분할 원통형 128채널 배열: 설계 검토 초안

이 문서는 사용자가 제시한 4개 CAD 이미지에 맞춘 설계 초안이다. 원통의 둘레를 4개 곡면 패널로 나누며 각 틈은 터널 길이 방향으로 이어진다. 길이 방향으로 원통을 4개 구간으로 자르는 구조가 아니다.

**현재 파일은 배치 검토용이다. 제작용 Gerber, 회로도, 확정 기구 도면은 포함하지 않는다. 실제 부양 성능과 새 회로의 동작은 아직 검증되지 않았다.**

## 1. 예시 치수와 배치

아직 사용자가 확정하지 않은 치수는 다음 예시를 사용했다. 단위는 mm이다.

| 항목 | 예시 값 | 의미 |
|---|---:|---|
| 음향 방사면 중심이 놓이는 원의 지름 | 100 | 지지대 내경이나 FPCB 지름과 구별해야 한다 |
| 배열 길이 | 160 | 커넥터 꼬리, 끝단 브래킷, 작업 여유는 별도 |
| 패널 사이 틈 | 8 | 방사면 반지름에서 측정하는 원호 길이; 직선 틈과 다름 |
| 송신기 외경 | 16 | V40AN16T를 후보로 사용 |
| 송신기 몸체 높이 | 12.5 | 핀 돌출 길이는 별도 |
| 패널 수 | 4 | 같은 구조를 90도씩 회전 |
| 패널당 개수 | 32 | 둘레 방향 4열 × 길이 방향 8개 |
| 전체 개수 | 128 | 송신기 1개마다 독립 출력 1개 |
| 길이 방향 중심 간격 | 20 | 16mm 몸체 사이에 명목상 4mm 여유 |
| 같은 패널의 둘레 방향 방사면 중심 직선거리 | 약 17.54 | 전체 몸체/프레임 간섭 검사를 대신하지 않음 |
| 송신기 후면 기준 반지름 | 62.5 | 방사면 반지름 50 + 몸체 높이 12.5 |
| 후면 원통을 이상적으로 펼친 패널 폭 | 약 88.17 | 실제 FPCB 외곽, 보강판, 평면 납땜 섬 설계에 따라 변경 |

방사면은 각 위치에서 원통의 중심축을 향한다. 각 방사면은 평평하므로, 실제 터널의 빈 공간은 완전한 원형 벽과 같지 않다. 방사면 모서리는 기준 원의 바깥쪽에 위치한다.

CSV의 원점은 앞쪽 끝면 중심이며 터널 축은 +Z이다. X/Y는 단면 좌표, normal은 안쪽을 향하는 단위벡터이다. 채널 번호는 `패널*32 + 둘레열*8 + 길이행`이다. 이는 새 설계를 위한 제안 번호이며 기존 FPGA 채널 번호와의 대응을 검증한 결과가 아니다.

## 2. 실제 제작 구조

권장 검토안은 **4개 기구 지지대 + 4개 FPCB 배열 + 외부 평면 드라이버 보드**이다.

- 기구 지지대에 송신기 몸체를 고정하고 하중을 받게 한다. 납땜 핀이 송신기의 무게와 조립 힘을 지탱하지 않도록 한다.
- FPCB의 송신기 핀 두 개가 들어가는 자리는 평평한 보강 영역으로 만든다. 보강 영역 사이만 휘도록 하고, 납땜 패드·관통홀·비아가 굽힘 구간에 들어가지 않게 설계한다.
- 부품을 평평하게 받치는 납땜 지그에서 조립한 뒤 지지대에 장착하는 공정을 검토한다. 이때도 보강 영역은 평평하게 유지해야 한다.
- 곡면 기준면과 평평한 부품 후면의 차이를 흡수하도록 FPCB에 연결부, 절개 또는 여유 길이를 설계한다. 단순 직사각형 FPCB를 휘어서 모든 송신기 핀에 끼울 수 있다고 가정하지 않는다.
- 드라이버 IC, 시프트 레지스터, 전원 커패시터는 외부 평면 PCB에 둔다. 방사면 앞에 부품이나 케이블이 나오지 않도록 한다.
- 일반 두꺼운 FR-4 기판을 이 반지름으로 강제로 휘는 방식은 채택하지 않는다. 대안은 각 패널을 여러 작은 평면 PCB로 구성하는 방식이다.

JLCPCB의 현재 공식 사양에는 FPCB와 보강판 옵션이 있지만 rigid-flex는 지원하지 않는다고 명시되어 있다. FPCB+보강판과 rigid-flex는 서로 다른 제작 방식이다. 이 업체를 최종 선정하거나 이 구조의 제조 가능성을 승인받은 상태는 아니다.

출처: [JLCPCB FPCB 제작 사양](https://jlcpcb.com/capabilities/flex-pcb-capabilities).

## 3. 전기 연결 제안

```text
PC의 위상 계산/전송
        ↓
FPGA: 연속 40kHz 출력 타이밍 생성
        ↓ 데이터·시프트 클록·래치 클록
외부 드라이버 PCB 4개, 각 32채널
        ↓ 패널마다 독립 출력 32개 + GND
곡면 FPCB 4개
        ↓
각 송신기: 한 핀은 해당 채널 OUT, 다른 핀은 GND
```

패널 하나를 담당하는 32채널 보드에는 74HCT595 4개와 TC4427A 듀얼 드라이버 16개를 사용하는 안을 검토한다. 전체로는 74HCT595 16개, 듀얼 드라이버 64개다. 두 드라이버 출력으로 송신기 하나를 구동하는 브리지 방식으로 바꾸면 필요한 IC 수가 달라진다.

FPGA는 3.3V 논리, HCT 레지스터는 5V 논리 전원으로 구성하는 안이다. TC4427A의 구동 전원은 별도로 공급하고 모든 보드의 GND를 공통으로 연결한다. 초기 구동 전압은 송신기 연속 구동 허용치와 실험 결과로 정한다. 송신기 데이터시트의 80Vpp impulse 수치를 연속 운전 정격으로 사용하지 않는다.

FPGA→드라이버 보드의 데이터는 보드마다 4줄, 전체 16줄을 제안한다. 클록은 모든 출력의 시간 기준을 맞추되 배선 길이와 부하에 맞게 버퍼와 직렬 저항을 검토한다. 기존 256채널 펌웨어를 그대로 써서 128채널이 정확히 대응한다고 가정하지 않는다.

드라이버→패널은 **2개의 20핀 연결부**를 예시로 검토할 수 있다. 각 연결부에 16개 독립 출력과 4개 GND를 배정하면 패널당 32개 출력과 8개 GND가 된다. 이는 핀 수 제안이며 커넥터 모델, 전류 정격, 케이블 길이, 핀 순서가 확정된 연결도가 아니다. 모든 송신기를 하나의 OUT에 병렬 연결하면 128개 독립 위상 제어가 불가능하다.

각 IC 가까이 0.1µF 디커플링을 두고 드라이버 전원에 추가 로컬 커패시터와 벌크 커패시터를 둔다. 최종 용량·배선 폭·커넥터 GND 수는 측정한 공급 전류, 출력 에지와 전원 리플에 맞춰 선정한다. 송신기 자체도 용량성 부하이며 전원 커패시터와 역할이 다르다.

회로 구조 근거: [원 논문](https://doi.org/10.3390/app11072981), [TC4427A 데이터시트](https://ww1.microchip.com/downloads/aemDocuments/documents/APID/ProductDocuments/DataSheets/TC4426A-TC4427A-TC4428A-1.5A-Dual-High-Speed-Power-MOSFET-Drivers-2000142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). 새 원통 배열, HCT 사용 및 보드 분리는 별도 설계 제안이다.

## 4. 검증 상태와 제작 순서

기존 SonicSurface의 10mm·256채널 Gerber에서 출력 연결을 정적으로 추적했다. 이 결과는 새 16mm·128채널 원통 배열의 기구 간섭, 실제 전압, 발열, 위상 정확도나 부양 성공을 보장하지 않는다. 기존 FPGA 헤더의 물리 핀 대응도 아직 확정된 제작 연결도가 없다.

1. 방사면 기준 지름, 길이, 틈의 기준과 폭, 부양할 입자 조건, 기판 방식을 확정한다.
2. 실물 송신기의 핀 간격·핀 굵기·높이와 음향 극성을 확인하고 1열 기구 샘플로 체결과 납땜성을 검토한다.
3. 새 배열 좌표와 방향으로 음장, 압력 구배 및 목표 입자의 안정성을 시뮬레이션한다. 중앙 압력 크기만으로 부양을 판정하지 않는다.
4. 8채널 회로 시제품에서 전원 투입/종료 상태, 출력 파형, 위상, 전원 리플과 온도 상승을 측정한다.
5. 32채널 패널에서 기구 간섭, FPCB 굽힘 및 고정, 커넥터/케이블 영향을 검증한다.
6. 회로도 ERC, PCB DRC, 제조사 FPCB·보강판 DFM을 통과한 뒤 4패널 제작 파일을 낸다.

## 5. 이번 파일

- `tunnel_4panels_128_CONCEPT.scad`: OpenSCAD에서 치수를 바꾸는 배치 모델. 지지대는 구멍만 포함한 예시이며 고정 탭·나사·실제 보강판은 미설계다. FPCB 기준면은 옵션으로만 표시한다.
- `tunnel_layout_CONCEPT.png`: 128개 방사면 배치와 단면 미리보기.
- `transducer_positions_CONCEPT.csv`: 128개 방사면 중심 좌표와 안쪽 방향. BOM 가격표가 아니다.
- `parameters_CONCEPT.json`: 예시 치수와 계산값, 제한 사항.

OpenSCAD를 실행해 렌더링한 결과는 아직 없다. PNG는 동일 배치 수식으로 별도 생성하고 시각적으로 확인했다. 예시 좌표의 128개 고유 채널 번호와 단위 방향벡터를 확인했다. 전체 기구 충돌 검사와 음향 시뮬레이션은 아직 수행하지 않았다.

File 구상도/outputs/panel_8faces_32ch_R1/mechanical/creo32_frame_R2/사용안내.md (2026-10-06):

# 32채널 PCB + 외부 프레임 Creo R2

기존 `creo_tunnel_reused_v2/build_geometry.py` 방식과 색상값을 사용했습니다. 기판 RGB(0.04,0.35,0.16), 프레임 RGB(0.30,0.32,0.36). 단품 STEP에도 색상을 넣어 Creo로 가져왔으며, 네이티브 저장→새 세션 재조회→STEP 재내보내기에서 실제 솔리드에 연결된 색상을 확인했습니다. 색상은 기구 모델의 외관 설정이며 PCB 제조업체의 솔더마스크 주문 설정은 별도입니다.

## 열 파일

- 전체 조립체: [native/tunnel8_32_r2.asm](native/tunnel8_32_r2.asm)
- 기판 조립체: [native/panel32_r2.asm](native/panel32_r2.asm)
- 진녹색 기판 단품: [native/pcb32_r2.prt](native/pcb32_r2.prt)
- 프레임 링 단품(동일 부품 2개): [native/ring8_32_r2.prt](native/ring8_32_r2.prt)
- 교환용 STEP: [geometry/tunnel8_32_r2.step](geometry/tunnel8_32_r2.step), [geometry/ring8_32_r2.step](geometry/ring8_32_r2.step)
- 미리보기: [tunnel8_model_preview.png](tunnel8_model_preview.png)

Creo의 작업 디렉터리를 `native`로 지정하고 전체 조립체를 여세요. 조립체와 모든 PRT를 같은 폴더에 두세요. Creo 9.0.10에서 생성·재조회했습니다. STEP에서 가져온 형상 피처이며 치수 구속 스케치로 만든 완전 파라메트릭 모델은 아닙니다. 부품 11종/조립체 2종, 기판 조립체 149개 구성요소, 최상위 조립체 8개 기판 조립체 + 링 2개입니다.

## 프레임 치수와 고정 방식

| 항목 | 치수 / 배치 |
|---|---|
| PCB | 84 × 224 × 1.6 mm, 위아래 고정 영역 22 mm |
| 발진면 사이 간격 | 기존 R1 선택값 210 mm 유지 |
| PCB 앞면 반경(아포템) | 117.5 mm |
| 팔각 링 외측/내측 대변 거리 | 265 / 231 mm |
| 링 두께 | 8 mm, 동일 부품 2개 |
| 링 배치 Z | 아래 −105..−97 mm, 위 97..105 mm |
| PCB 삽입 슬롯 | 각 링 8개, 길이 84.6 × 두께 2.2 mm, 링 높이 관통 |
| 슬롯 여유 | PCB 양면 및 양끝 각각 0.3 mm |
| M3 체결 구멍 | Ø3.2 mm, 각 링 16개 / 총 32개, 방사 방향 관통 |
| 구멍 위치 | 각 면 중앙에서 접선 방향 ±36 mm, 조립체 Z ±101 mm |
| 전체 프레임 포함 외형 | 265 × 265 × 224 mm; 볼트·너트 제외 |
| 링 사이 열린 높이 | 194 mm |

팔각형 꼭짓점 간 최대 폭은 대변 거리보다 큽니다(약 286.83 mm). 265 × 265 mm는 모델 X/Y축의 외접 치수입니다. 링 하나의 방사 방향 벽 폭은 17 mm입니다. 체결 위치는 PCB의 (6,11), (78,11), (6,213), (78,213) 구멍에 맞췄습니다. Z=0은 기판 높이의 중앙이고 +Z가 위쪽입니다. 링 단품 좌표는 Z=0..8 mm이며 체결 구멍 중심은 Z=4 mm입니다. `frame_mount_bores.csv`에 단품의 16개 구멍 축 좌표가 있습니다.

상하 링을 기판 고정 영역에 끼우고 M3 볼트/너트로 방사 방향 구멍과 PCB 구멍을 관통 체결하는 구조입니다. 재질, 와셔, 볼트 길이, 체결 토크는 확정하지 않았고 체결 부품은 모델에 포함하지 않았습니다. 슬롯은 끼움 여유를 가지므로 실물 치수와 재질에 따라 얇은 시임으로 유격을 조절할 수 있습니다. 가공 시 방사 방향 구멍은 측면 가공이 필요합니다. 밀링 슬롯의 코너 반경/끝단 여유는 공구와 PCB 모서리 형상에 맞춰 제조업체에서 검토해야 합니다. 3D 프린팅은 수축/공차를 반영한 시험 조립이 필요합니다.

## 촬영용 틈과 확인 범위

중간 높이에 세로 프레임 기둥을 넣지 않았으며, R1의 인접 PCB 앞면 모서리 사이 약 12.325 mm 틈을 유지했습니다. 연속 팔각 링은 상하 끝의 고정 영역만 감쌉니다. 전체 물체가 보이는지는 물체 크기·위치, 카메라 렌즈·궤적이 정해져야 확인할 수 있습니다. 회전 카메라, 케이블, 베어링/구동 장치는 포함하지 않았습니다.

기판과 부품에 대한 링 교차 체적 0건, 고정 구멍 축 정렬, STEP 재조회 1194개 솔리드, Creo 새 세션의 단위·외형·149/10개 참조·배치·고정 상태, 네이티브 단품 11종의 실제 STEP 외형/체적/솔리드 색상 연결을 확인했습니다. 검증 기록은 `geometry_checks.json`, `validation/native_reopen_report.json`, `validation/native_STEP_roundtrip.json`에 있습니다. 실제 Creo 창의 화면 캡처 대신 API 저장·조회와 STEP 재내보내기로 검증했으며 PNG는 STEP 형상을 렌더한 미리보기입니다.

기판 외곽과 98개 부품/고정 구멍은 기존 R1 데이터를 그대로 사용했습니다. 부품 몸체는 근사 외형이며 동박/실크/비아 구멍은 이 모델에 포함하지 않았습니다. 실제 부품·커넥터·납땜·전선의 공차 및 강도/진동/열/음향 성능은 미검증입니다. 이전 Creo R1 폴더와 원본 KiCad PCB의 SHA-256 불변을 확인했습니다.

재생성 스크립트: `구상도/scratch/build_creo32_frame_r2.py`, `prepare_creo32_frame_r2.py`, `verify_creo32_frame_r2.py`, `render_creo32_frame_r2.py`, `finalize_creo32_frame_r2.py`. 형상/렌더링은 프로젝트의 `creo32_env` 환경을 사용하며, Creo API HTML/스크립트는 `creo32_frame_session`에 있습니다.

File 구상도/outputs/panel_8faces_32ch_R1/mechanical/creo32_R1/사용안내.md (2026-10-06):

# 32채널 PCB R1 — Creo 모델

KiCad R1의 현재 기판과 부품 배치를 사용한 새 모델입니다. 기존 Creo 파일과 KiCad 회로/배선은 변경하지 않았습니다. Creo Parametric Educational Edition 9.0.10.0에서 실제 `.prt`·`.asm`을 생성하고, 새 세션에서 저장 파일을 다시 불러와 검증했습니다.

## Creo에서 여는 파일

`native` 폴더를 작업 디렉터리로 지정하고 아래 파일을 엽니다. 조립 파일을 다른 곳으로 옮길 때는 `native`의 12개 파일을 모두 함께 복사하세요.

| 파일 | 내용 |
|---|---|
| `pcb32_r1.prt` | 84 × 224 × 1.6 mm 기판 단품, 고정홀4개 및 부품용 구멍94개 |
| `panel32_r1.asm` | PCB1장 + 트랜스듀서32개 + 후면부품116개, 직접 구성요소149개 |
| `tunnel8_32_r1.asm` | 위 기판 조립체8개, 트랜스듀서총256개, 총1192개 솔리드 |
| `tx16_r1.prt` | 지름16 mm·높이12.5 mm 트랜스듀서 몸체 근사 |
| 나머지8개 PRT | 저항·MLCC·SOIC16/8·SOT23·전해콘덴서·헤더2종의 공유 근사 외형 |

단품은10종, 조립체는2종입니다. 후면공유부품은 `r0805_r1`, `c0805_r1`, `so16_r1`, `so8_r1`, `sot23_r1`, `cp63_r1`, `hdr10_r1`, `hdr3_r1`입니다.

## 형상과 좌표

- 기판 로컬 좌표: X=폭0…84 mm, Y=길이0…224 mm, Z=두께0…1.6 mm. 안쪽/트랜스듀서 면은Z=0이며 소자는Z=-12.5…0 mm에 있습니다. 후면 부품은Z≥1.6 mm에 배치합니다.
- 트랜스듀서 열중심X=13,31,53,71 mm, 행중심Y=42,62,…182 mm. 열간격18–22–18 mm, 행간격20 mm.
- 위아래 고정여백은각22 mm. M3 고정홀은지름3.2 mm, (6,11),(78,11),(6,213),(78,213) mm입니다.
- 8면 조립체: 세계Z=0은기판높이중앙, 각면45°. PCB안쪽면의중심거리117.5 mm, 발진면은105 mm로 마주보는발진면간격210 mm입니다. 기판모서리틈약12.325 mm입니다.
- 후면부품 포함모델 외접크기는260.2 × 260.2 × 224 mm입니다. 부품 근사모델 기준이며 커넥터에 꽂히는 케이블/플러그는 미포함입니다.
- 기판에는실제부품패드/고정용98개구멍이있습니다. 전기설계의206개비아, 동박트랙, 솔더마스크표면텍스처와 실크는기계모델에서생략했습니다.

## 모델 정확도와 편집

기판 외곽·두께·부품구멍과실제풋프린트위치는KiCad로부터검증했습니다. 부품은기구배치를보는단순몸체모델입니다. TX캔/메시/내부진동판, IC리드, 헤더개별핀, 전해콘덴서극성표시, 소자납땜높이는정밀제조사CAD가아닙니다. 실제구매품으로체결/케이블간섭을최종확인해야합니다.

PRT는 STEP에서 가져온 솔리드와 가져오기 피처입니다. Creo의 네이티브 스케치·돌출 치수로 전체 설계가 파라미터화되어 있는 것은 아닙니다. 조립체는 같은 공유 PRT를 재사용하고 각 부품/면에 Fix 구속을 적용했습니다. 위치를 바꾸려면 해당 Fix 구속을 수정하거나 다른 구속으로 바꾸면 됩니다. 기판 치수나 부품 외형 변경은 제공 생성 스크립트에서 재생성하거나 Creo 직접 편집을 사용할 수 있습니다.

## STEP 및 미리보기

`geometry/pcb32_r1.step`, `panel32_r1.step`, `tunnel8_32_r1.step`도 제공합니다. 표준 교환형식 STEP는 [CadQuery 공식 내보내기 문서](https://cadquery.readthedocs.io/en/latest/importexport.html)의 방식으로 만들었습니다. `panel32_model_preview.png`는 실 STEP 솔리드의앞뒤외형, `tunnel8_model_preview.png`는8면배치입니다. PNG는 Creo 화면캡처가 아닌 실제STEP형상을렌더링한미리보기입니다. 색상은이해를돕는표시이며실물외관을보장하지않습니다.

## 검증

- CadQuery2.8.0/OCP7.9.3.1.1: 솔리드 유효성, 전부품/조립STEP재가져오기, 구멍98개와정확한기판체적, 모든TX발진면중심의음향좌표일치 확인.
- 기판조립체의모델솔리드교차체적검사0건. 인접면은전체모델을포함하는각도구간이겹치지않음을보수적외접범위로증명했습니다. 이는 모델에 포함된 형상에 대한 검사입니다.
- Creo새세션: 부품10종 단위·체적, 기판/상자외형치수, 원통의 정확한 STEP 외형·체적, 기판조립체149개및면조립체8개의모델참조·행렬·비패키징상태를검증했습니다. 원통XY `GeomOutline`은 보수적경계를반환할수있어Creo에서 부품을 다시 STEP로 내보내 정확한 외형과 체적을 독립검증했습니다. 실제수치는`validation/native_reopen_report.json`에보관합니다.
- 기판및8면조립체외접치수는CreoAPI와STEP모델을대조했습니다. 실제CreoGUI화면캡처는환경의창검색제약으로확인하지않았으며CreoAPI의저장/재조회결과를사용했습니다.
- 원본KiCadPCB SHA-256 유지. 외부프레임/회전카메라/케이블이없는조건의기계형상검사이며열·음향부상·전체물체촬영검증은포함하지않습니다.

`geometry_checks.json`, `pcb_geometry_input.json`, `validation/`은좌표/단위/검증근거입니다. `Creo32_R1_models.zip`에는native·STEP·PNG·검증기록이함께들어있습니다. STEP에서읽은부품이름과부품방향을확인한뒤실제기구설계에사용하세요.

## 재생성

프로젝트 `구상도/scratch`의 `extract_creo32_r1.py`(KiCad내장Python), `prepare_creo32_r1.py`, `build_creo32_geometry.py`, `verify_creo32_native.py`, `render_creo32_vtk.py`, `finalize_creo32_r1.py`를사용했습니다. 기하생성/렌더에는같은위치의프로젝트전용 `creo32_env` 환경을사용했습니다. Creo생성용스크립트/HTML은 `creo32_session`에있고, 한글경로호환성을위해Temp의두ASCII정션으로동일프로젝트파일을참조했습니다. 산출물의원본파일은이프로젝트안에만있습니다.

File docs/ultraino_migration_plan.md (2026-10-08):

# Creo 8면 32채널 터널 기준 Ultraino 이식 작업 계획

2026-10-07 사용자 지시에 따라 현재 개발 기준을 **8면, 면당 PCB 1장, PCB당 트랜스듀서 32개, 총 8기판·256채널**로 확정한다. 현재 Creo R2의 배치와 일치하는 배열을 AcousticStudio에 추가하고, 그 배열을 공통 입력으로 Ultraino의 다중 트랩·방사력 분석·조작·캘리브레이션 기능을 이식한다.

이 문서는 이후 에이전트의 구현 기준이다. T0 계산 경로, T1 CAD 배열, T2 복소 음장, T3 방사력 분석, T4 다중 트랩, T5 통신·캘리브레이션, T6 단면 조작·궤적 이송의 소프트웨어 구현과 검증을 완료했다. [T0 기록](ultraino_t0_result.md), [T1 기록](ultraino_t1_result.md), [T2 기록](ultraino_t2_result.md), [T3 기록](ultraino_t3_result.md), [T4 기록](ultraino_t4_result.md), [T5 기록](ultraino_t5_result.md), [T6 기록](ultraino_t6_result.md)을 확인한다. 다음 단계는 사용자 요청에 따른 T7 실물 검증이다. 실제 펌웨어·배선·OFF/파형 측정은 미완료다. 사용자의 최신 지시가 과거 보고서·안내의 8면 16기판 구성을 대체한다.

## 작업 시작 순서

1. [AGENTS.md](../AGENTS.md), 이 문서, [진행 기록](project_status.txt)을 읽는다.
2. `git status --short`와 관련 소스를 확인하고 기존 사용자 변경을 보존한다.
3. [점검 결과 JSON](ultraino_migration_audit.json)에서 형상 및 인터프리터 근거를 확인한다. 날짜·해시가 달라졌다면 입력을 다시 확인한다.
4. 완료된 작업의 검증 기록을 확인하고 첫 미완료 단계부터 작업한다. 현재 T0~T6 소프트웨어 완료, 다음은 T7 실물 검증이다. T5 실제 하드웨어 검증은 사용자 요청 실물 단계에서 수행한다. 각 작업의 산출물과 완료 기준을 만족한 후 의존하는 작업으로 넘어간다.
5. 구현 후 진행 기록에 변경·실행한 검증·남은 한계를 기록한다. 다른 에이전트에게 맡길 때 작업 ID, 파일 범위, 완료 기준, 실제 검증 결과를 전달한다.

사용자 승인 전 `backup/`을 갱신하지 않으며, 명시적 요청 없이 commit/push하지 않는다. 이 계획 자체가 실제 보드 송신이나 CAD 재생성의 실행 요청은 아니다.

## 현재 형상과 입력의 우선순위

| 용도 | 현재 기준 파일 |
| --- | --- |
| Creo 전체 조립체 | [tunnel8_32_r2.asm](../구상도/outputs/panel_8faces_32ch_R1/mechanical/creo32_frame_R2/native/tunnel8_32_r2.asm) |
| Creo 기판 조립체 | [panel32_r2.asm](../구상도/outputs/panel_8faces_32ch_R1/mechanical/creo32_frame_R2/native/panel32_r2.asm) |
| 256개 방사면 중심과 법선 | [array_positions_256.json](../구상도/outputs/panel_8faces_32ch_R1/array_positions_256.json) |
| PCB 치수와 배열 설정 | [parameters.json](../구상도/outputs/panel_8faces_32ch_R1/parameters.json) |
| Creo 부품 및 면 배치 행렬 | [geometry_checks.json](../구상도/outputs/panel_8faces_32ch_R1/mechanical/creo32_frame_R2/geometry_checks.json) |
| Creo 저장 후 재조회 배치 근거 | [native_reopen_report.json](../구상도/outputs/panel_8faces_32ch_R1/mechanical/creo32_frame_R2/validation/native_reopen_report.json) |
| 전체 채널의 행·열·뱅크 연결 | [channel_map.csv](../구상도/outputs/panel_8faces_32ch_R1/channel_map.csv) |
| 물리 채널에서 소프트웨어 채널로의 후보 맵 | [physical_to_software_channel_map.json](../구상도/outputs/panel_8faces_32ch_R1/physical_to_software_channel_map.json) |
| R2 형상 사용 안내 | [Creo R2 사용안내](../구상도/outputs/panel_8faces_32ch_R1/mechanical/creo32_frame_R2/사용안내.md) |
| 원래 조사 보고서 | [초음파부상 및 Ultraino 기능통합 분석보고서](<../../보고서 및 구체화/초음파부상_역장제어_및_Ultraino_기능통합_분석보고서.docx>) |

CAD 입력은 새로 생성하지 않고 기존 파일을 읽는다. 실행 시에는 배포 가능한 배열 JSON을 사용하며 Creo, KiCad, CadQuery 또는 STEP 변환기를 앱 필수 의존성으로 만들지 않는다. STEP 표시가 필요하면 별도 선택 기능으로 추가한다.

`구상도/creo_tunnel/v1_single_panel`의 8기판·128개와 `v2_dual_panel`의 16기판·256개는 이전 설계다. 이 폴더와 과거 검증 기록은 보존하되 현재 배열 입력으로 사용하지 않는다. `parameters.json`의 revision R1은 PCB 개정이며, Creo 프레임 R2와 충돌하지 않는다.

## 반드시 재현할 배치

| 항목 | 현재 값 |
| --- | --- |
| 면 및 채널 | 8면 × 1기판 × 32채널 = 256채널 |
| 한 기판의 배열 | 4열 × 8행, 지름 16 mm 트랜스듀서 |
| PCB 크기 | 84 × 224 × 1.6 mm |
| 터널 축 및 수직 방향 | Z축, 원점은 터널 중심 및 기판 높이 중앙 |
| 면 방향 | 면 0은 +X측, 이후 +Z에서 내려다본 XY 평면 기준 45°씩 회전 |
| 발진면 아포템 | 105 mm, 마주 보는 발진면 거리 210 mm |
| PCB 앞면 아포템 | 117.5 mm, 트랜스듀서 높이 12.5 mm |
| 기판 접선 방향 좌표 | −29, −11, 11, 29 mm, 간격 18/22/18 mm |
| 축 방향 좌표 | −70, −50, −30, −10, 10, 30, 50, 70 mm |
| 법선 | 각 면에서 터널 중심을 향하는 수평 단위 벡터 |
| 외부 프레임 | 링 2개, Z −105..−97 및 97..105 mm, 전체 외형 265 × 265 × 224 mm |
| 전기적 뱅크 | PCB당 A/B 16채널씩, 전체 16뱅크 |

면 f의 각도를 θ=fπ/4, 외향 벡터를 n=(cosθ,sinθ,0), 접선 벡터를 t=(−sinθ,cosθ,0)로 두면 기존 좌표는 `position_mm = 105*n + u*t + (0,0,z)`이고, 발진 법선은 `normal = -n`이다. u와 z는 위 표의 값이다. 면 0의 T1은 `(105,−29,−70)`, 법선은 `(−1,0,0)`이다. 실제 로더는 JSON을 읽고 이 식은 검증에 사용한다.

소프트웨어 채널은 `channel=32*face+local_channel`, `local_channel=4*row+column`, T1..T32는 각 기판에서 반복한다. 영구 식별자는 face와 local_channel의 조합을 사용한다. 소프트웨어 행 우선 순서와 물리 전송 순서는 다르므로 후보 맵을 항등 맵으로 대체하지 않는다.

Creo JSON의 행렬은 **행 벡터와 마지막 행의 평행이동** 규약이다. `[x,y,z,1] @ T`를 사용한다. VTK의 열 벡터 규약에 적용할 때는 전치/변환 어댑터를 거쳐 검증한다. 트랜스듀서 단품 로컬 발진면은 z=−12.5이고 법선은 −Z다. mesh의 외접 상자 중심이나 PCB 위치를 방사면 중심으로 사용하지 않는다.

이번 점검에서 256개 위치·법선을 R2 배치 행렬로 재계산하고 Creo 재조회 기록과 비교했다. 위치 최대 오차는 약 5.61e−14 mm이며, 네이티브 ASM/PRT 13개의 현재 해시가 기존 manifest와 일치했다. 이는 저장된 모델과 입력 파일의 일치 확인이며, 현재 열린 Creo의 저장하지 않은 변경이나 실제 부양 성능을 확인한 것은 아니다.

## 기존 기능과 작업 환경의 재사용

| 기존 자산 | 재사용할 부분 | 추가하거나 수정할 부분 |
| --- | --- | --- |
| `app.py::generate_array()` | 일반 Matrix, Tube, 대향형, 반구형 생성 및 렌더링 | 고정 CAD 프리셋 로더 추가. 기존 Tube의 X축 링 배치·균일 간격으로 현재 형상을 생성하지 않는다 |
| `PhaseEngine` | 계산 진입점, 연산 모드 선택, 기존 Twin/Vortex | 좌표·법선·개구 전달, 공통 복소 음장 및 Kinoforms 경로 |
| `sonic_wrapper.py`, `sonic_core.cpp`, DLL | 기존 CPU/native/GPU 가속 경로 | T0 호출 수정 후 동일 모델의 수치 비교. 신규 기능의 지원 여부를 명시 |
| `hardware.py` | BoardProfile, 양자화, 프레임 인코더, `set_channel_map()` | 후보 맵 검토, 보정 및 OFF, 실제 펌웨어 프로파일 |
| `MouseEventFilter`, 자동 계산, 실시간 전송 | 선택·기즈모·자동 계산 연결 | 단면 피킹, XYZ 스텝 이동, 요청 취소 및 송신 속도 제한 |
| `file_io.py`, `get_state()/set_state()`, `StateManager` | JSON 입출력, Undo/Redo | 배열 메타데이터·법선·개별 모델·캘리브레이션 저장과 이전 파일 호환 |
| `kwave_engine.py` | 기존 2D 해석 창 | 필요할 때 같은 CAD 입력을 전달. Kinoforms 이식의 선행조건으로 삼지 않는다 |
| `ui_appearance.py` | 클래식/모던 UI와 공통 보드 메뉴 | 두 UI에 동일한 기능 연결. 별도 메인 창·렌더러를 만들지 않는다 |
| 기존 배열 JSON 및 Creo 생성 스크립트 | 확인된 좌표와 형상 근거 | 새 CAD 생성기와 좌표 파일을 중복 작성하지 않는다 |
| 기존 테스트 | `test_hardware_profiles.py`, `test_ui_appearance.py` | 형상·계산·보정·프로토콜의 실제 회귀 위험을 검증하는 테스트 추가 |

초기 점검에서는 단면 방향성 누락, ±Z 법선 추정, 계산 실패의 기본 '안정' 반환을 확인했다. T0/T2에서 실패 표시와 CAD 법선·선택 방향성 연결을 수정했다. 현재 상대 stiffness norm은 복원 부호·중력 평형·실측 음압을 검증하지 않으므로 T3 방사력 분석과 구분한다.

### 확인한 인터프리터

| 환경 | 확인 결과 | 작업 방침 |
| --- | --- | --- |
| `C:/Users/line0/anaconda3/python.exe` | Python 3.13.9. NumPy 2.2.6, Numba 0.62.1, PySide6 6.9.2, PyVista 0.49.0, PyVistaQt 0.13.1, VTK 9.7.0, matplotlib 3.10.9, levitate 3.0.0, pyserial 3.5, pytest 8.4.2 등 설치. 핵심 모듈 10개 import 성공 | 현재 기계의 개발·검증 기준. 경로를 명시하여 사용하며 일괄 재설치하지 않는다 |
| `py`의 기본 Python | Python 3.14.6, 점검한 앱 패키지 미설치 | `py main.py` 또는 경로 없는 기본 `py -m pytest`로 환경을 판단하지 않는다 |
| `구상도/scratch/creo_cad_env/Scripts/python.exe` | Python 3.13.9. CadQuery 2.8.0, cadquery-ocp 7.9.3.1.1, NumPy 2.5.3, VTK 9.6.2. 앱용 Qt·levitate 등은 미설치 | CAD 변환용으로 보존. 앱 패키지를 여기 설치하거나 이 환경을 앱 환경으로 사용하지 않는다 |
| Anaconda의 `sixsense` | Python 3.9.25, 점검한 앱 패키지 대부분 미설치 | 다른 용도의 기존 환경으로 보존 |
| 저장소의 `.venv` 및 `venv` | 현재 없음 | 기존 앱 환경으로 작업 가능. 격리가 실제 필요할 때 검증한 의존성으로 별도 환경을 구성한다 |

`creo32_env`라는 경로가 R2 안내와 `.gitignore`에 남아 있지만 현재 존재하지 않는다. CAD 환경의 현존 경로는 위 표의 `creo_cad_env`다. 복사된 `pyvenv.cfg`의 과거 생성 경로만 보고 환경을 이동·재생성하지 않는다.

앱과 CAD 환경에는 NumPy/VTK 등이 각각 다른 버전으로 설치되어 있다. 용도가 분리된 환경이므로 합치지 않는다. 앱 기능 이식에는 이미 설치된 NumPy/Numba/Qt/matplotlib/pyserial을 사용한다. 초기 점검은 Torch/Taichi 설치 메타데이터만 확인했으며, T2/T3/T4에서 Taichi 1.7.4의 실제 CUDA 복소 합산을 검증했다. 설치된 PyTorch 2.14.0은 CUDA build가 없어 CPU 전환만 검증했다. SciPy 1.15.3은 T2부터 공통 모델에 사용한다. k-wave-python 0.6.3rc1은 설치되어 있지만 solver 실행 검증은 포함하지 않는다. T4 원본 비교는 기존 OpenJDK 25.0.4.1을 사용했으며 Java/NetBeans는 Python 앱 실행의 필수 환경이 아니다. T2는 기존 MSVC로 DLL을 재빌드했고 T3/T4는 같은 DLL을 재사용했다. 추가 환경·패키지를 설치하지 않았다.

초기 점검에서 `requirements.txt`의 `numba` 누락과 `main.py` 점검 목록의 불일치를 확인했고 T0에서 필수 의존성 10개를 공통 카탈로그와 일치시켰다. 확인한 앱 패키지 버전은 `requirements-tested.txt`에 기록했다. 사용자 Anaconda 전체 환경을 freeze하여 프로젝트 요구사항으로 복사하지 않는다. 새 머신에서는 표의 설치 상태를 보장할 수 없으므로 선택한 인터프리터로 다시 점검한다.

점검 명령은 저장소 루트에서 실행한다. 아래 스크립트는 입력 파일을 읽고, `--out`으로 지정한 점검 JSON만 갱신한다.

```powershell
$studioPython = 'C:/Users/line0/anaconda3/python.exe'
& $studioPython scratch/ultraino_migration/audit_inputs.py --check-app-imports --out docs/ultraino_migration_audit.json
```

다른 환경을 함께 기록하려면 `--probe-python <python.exe>`를 반복 지정한다. 현재 점검 JSON에는 앱, 기본 py, CAD, sixsense 4개 환경이 기록되어 있다. 위 기본 명령으로 갱신하면 실행 인터프리터만 기록되므로 기존 비교를 유지하려면 같은 3개 보조 인터프리터를 다시 지정한다. 문서 작업을 위해 `main.py`를 실행하지 않는다. 시작 시 설치 UI가 뜰 수 있다.

## 공통 데이터와 모듈 계약

UI의 actor를 계산 데이터의 원본으로 사용하지 않는다. 로더가 만든 배열 데이터가 계산·시각화·저장·송신의 공통 원본이며, actor는 표현과 선택을 담당한다.

- 배열: `geometry_id`, `schema_version`, 원본 경로/해시, 좌표계/단위, 256개 송신기. 송신기는 ID, face, local_channel, row, column, position_mm, normal, aperture, frequency, 모델, 구동 진폭, 활성 상태를 가진다.
- 물리 조건: 매질 음속/밀도, 입자 반경·밀도·음속, 음압 스케일 및 출처. CAD 외경 16 mm만으로 유효 음향 개구 반경을 확정하지 않는다.
- 위상 결과: shape `(N,)`, rad, 유한값, 소프트웨어 채널 순서. 빈 배열·영 진폭·미지원 알고리즘·계산 실패를 명시한다.
- 제어점: ID, position_mm, trap_type, orientation, target_weight. 원본 Java의 색상 기반 트랩 유형을 명시적 필드로 바꾼다.
- 보정: 소프트웨어 채널 순서의 위상 오프셋(rad), 보정 ID, 측정 조건, 기하/보드/배선 버전. 물리 맵은 `map[physical_channel]=software_channel`이다.
- 송신: 계산 위상 → 소프트웨어 채널별 보정 → 위상 및 활성 상태의 물리 채널 매핑 → 프로파일별 양자화/OFF → 인코딩. 실시간과 파일 내보내기가 같은 경로를 사용한다.
- 저장: 배열과 보정 메타데이터, 송신 프로파일을 기록하고 이전 `test1.json`을 읽는 이행 경로를 제공한다. Undo/Redo에서도 배열 메타데이터가 소실되지 않아야 한다.

새 파일은 필요 범위에만 추가한다. `geometry.py`의 CAD 배열 로딩·검증과 `geometry_scene.py`의 VTK 어댑터는 T1, `field_model.py`와 `field_backends.py`의 공통 복소 전파·합산은 T2, `force_analysis.py`와 `force_analysis_ui.py`의 고정 위상 힘/퍼텐셜 분석은 T3에서 구현했다. T4는 `hologram.py`의 가상점/IBP와 `hologram_ui.py`의 취소·최신 요청 관리 및 설계 UI를 추가했다. T5는 `calibration.py`의 상대 보정/출처/배열 서명과 `calibration_ui.py`의 수동 편집·OFF 파일을 추가하고 기존 hardware.py/trajectory_export.py를 확장했다. PhaseEngine은 계산 진입점, hardware.py는 전송 책임, app.py/widgets.py는 UI 연결을 유지한다. 외부 라이브러리나 별도 위상 엔진·시리얼 컨트롤러를 중복 도입하지 않는다.

## 작업 단위와 완료 기준

### T0 기존 계산 경로와 의존성 선언 수정

상태: **구현 및 소프트웨어 검증 완료**. [상세 결과와 재현 명령](ultraino_t0_result.md). 전체 테스트 58개 통과. CAD 배열 연결과 물리 모델의 정확성은 이후 단계의 범위다.

관련 파일: [phase_engine.py](../src/acousticstudio/phase_engine.py), [sonic_wrapper.py](../src/acousticstudio/sonic_wrapper.py), [app.py](../src/acousticstudio/app.py), [hardware.py](../src/acousticstudio/hardware.py), [requirements.txt](../requirements.txt), [main.py](../main.py), [installer_ui.py](../src/acousticstudio/installer_ui.py).

`calculate_phases_sonic(cx,cy,cz,tx,ty,tz,...)`의 cx/cy/cz는 송신기, tx/ty/tz는 목표점이다. T0에서 궤적 최적화·내보내기의 뒤집힌 호출을 공통 PhaseEngine 진입점으로 교체했고 DLL 부재 시 NumPy 경로를 사용한다. 물리 계산 실패·빈 입력은 진단 불가로 표시하며 75/60% 기본 안정 판정을 제거했다. 일반 `.bin`은 선택 프로파일 프레임을 사용하고 이전 0xFA 파일은 `.legacy.bin`으로 구분한다. HardwareController의 보정·채널 매핑 경로를 송신과 내보내기에서 한 번씩 사용한다. 의존성 9개 선언과 두 설치 화면의 공통 카탈로그를 맞췄으며 일괄 재설치는 수행하지 않았다. 보정 측정·UI·영구 저장 및 OFF 처리는 T5에 남아 있다.

완료 기준: 서로 다른 송신기/목표점 개수로 출력이 `(N,)`인지 검증, DLL 없음·계산 오류·빈 입력 처리, 송신/내보내기 일치, 기존 보드 프로파일 테스트 유지. 아직 물리 정확성이나 CAD 배열 UI 완료로 기록하지 않는다.

### T1 Creo 배열 로더와 프리셋 연결

상태: **구현 및 소프트웨어 검증 완료**. [상세 결과와 재현 명령](ultraino_t1_result.md). 전체 테스트 76개 통과, 실제 Qt 프리셋 선택·저장/복원 확인, 독립 VTK 장면 렌더링 확인. Qt offscreen의 OpenGL 캡처 제약은 기록에 구분했다.

의존: T0. 구현 파일은 `geometry.py`, VTK 어댑터 `geometry_scene.py`, app.py의 구성/렌더링 및 get_state/set_state다. CAD JSON을 읽고 원본 해시와 256개 방사면 좌표·법선·ID, 구조물 행렬을 모델에 보존한다. 계산에는 CAD 모델 좌표를 사용하고 actor는 표시와 선택·변환의 어댑터로 사용한다. 이전 프로젝트는 기존 좌표 어댑터로 읽는다.

기존 `array_positions_256.json`에서 배열을 읽고 UI에 **Creo 8면 터널 8기판 32채널** 프리셋을 추가한다. 입력 경로는 실행 CWD와 Windows 사용자 이름에 의존하지 않도록 저장소/패키지 기준으로 해석한다. 배포용 배열 데이터가 필요하면 원본 해시를 함께 기록하며 CAD 전체를 복제하지 않는다. 단일 Spacing 입력으로 열 간격을 재생성하지 않는다. 고정 프리셋을 일반 Tube와 구분하며 현재 CAD를 바꾸는 치수 편집은 별도 기능으로 남긴다. 8개의 PCB와 필요한 프레임 표시는 재사용한 행렬·치수로 구성하고 256개 트랜스듀서는 방사면 위치와 법선에 맞춘다. 전체 위치·회전 변환을 적용하면 좌표와 법선도 함께 변환한다. 복잡한 STEP 솔리드 전체의 import를 초기 기능의 필수 조건으로 삼지 않는다.

완료 기준: 8면/32개/256개 수량, 비균일 열 간격, Z축, 내향 법선, CAD 입력 좌표 일치. VTK 어댑터에서 한 개와 대향 면의 방사면을 확인한다. 전체 회전/이동 및 저장·복원/Undo 후 동일한 ID·좌표·법선·채널 순서를 유지한다. 후보 물리 맵의 적용은 T5에서 다룬다.

### T2 공통 복소 음장과 방향성 모델

상태: **구현 및 소프트웨어 검증 완료**. [상세 결과·데이터 계약·T3 인계](ultraino_t2_result.md). 전체 116개 통과, PyTorch CUDA 3개 skip. NumPy/Numba/C++/실제 Taichi CUDA와 Levitate 음압을 비교했다. SciPy를 포함한 필수 선언 10개는 기존 설치 환경과 일치한다.

의존: T1. PhaseEngine과 신규 field_model.py가 위치·법선·개구·진폭을 공통으로 받도록 한다.

Ultraino의 [CalcField.java](../../simulations/Ultraino/AcousticFieldSim/src/acousticfield3d/algorithms/CalcField.java)의 전파 계산을 NumPy 기준 구현으로 옮긴다. Ultraino의 sinc 모델과 levitate CircularPiston 모델은 다르므로 모드를 명시하고 같은 모델·단위·음압 스케일끼리 비교한다. NumPy `sinc`의 π 정규화와 Java `sin(x)/x` 규약을 맞춘다. 계산 내부의 SI 경계와 위상 rad를 명확히 한다. levitate의 ±Z 법선 추정 및 모든 소자 유효 반경 0.005 m 고정을 CAD/음향 모델 입력으로 교체한다.

완료 기준: 단일 송신기 위상·거리·방향성 기준값, 대칭 배열과 전체 좌표 변환에서 일관성, NaN/무한대·근접 특이점 처리. 기존 10/16 mm·랑주뱅 표현은 유지하되 경험적 진폭을 측정 음압으로 표시하지 않는다. CPU 기준 검증 후 지원하는 native/GPU 경로를 같은 모델로 맞춘다.

### T3 고정 위상에서의 방사력 분석

상태: **구현 및 소프트웨어 검증 완료**. [상세 결과·계산 계약·T4 인계](ultraino_t3_result.md). 전체 143개 통과, PyTorch CUDA 3개 skip. 독립 정상파 해석식·Levitate 고르코프·전체 결합 행렬·미분 수렴·명목 중력 조건 및 실제 Qt worker의 계산·취소·닫기·출력을 확인했다. 실제 음압 미보정으로 물리 중력 평형/부양 판정은 보류한다.

의존: T2. 구현 파일은 force_analysis.py, force_analysis_ui.py와 app.py의 버튼·프로젝트 설정 연결이다. T2 전파·현재 위상/진폭을 고정한 FieldSnapshot을 재사용한다.

[CalcField.java](../../simulations/Ultraino/AcousticFieldSim/src/acousticfield3d/algorithms/CalcField.java)와 [ForcePlotsFrame.java](../../simulations/Ultraino/AcousticFieldSim/src/acousticfield3d/gui/misc/ForcePlotsFrame.java)의 고르코프 상수·수치 미분·변위 스캔을 옮긴다. 위상은 고정하고 입자 위치만 이동한다. F=−∇U, 복원 스티프니스 K=−∂F/∂x의 부호를 명시한다. levitate와 원본의 force-gradient 값은 K와 부호가 다를 수 있으므로 정합화한다. 강도 norm만으로 안정성을 판정하지 않는다. 축별 곡선부터 구현하고 결합 방향 안정성을 주장할 때는 전체 행렬을 확인한다.

완료 기준: 대칭 기준에서 힘의 대칭·복원 부호, 입자 물성 입력, 미분 간격 변경 수렴, 중력을 포함한 평형 조건, 같은 음장/모델의 기준값 비교. 절대 음압 보정 전 힘의 단위를 실측 성능으로 해석하지 않는다. 2D k-Wave 결과를 3D 부양 검증으로 사용하지 않는다.

### T4 Kinoforms와 다중 트랩

상태: **구현 및 소프트웨어 검증 완료**. [상세 결과·사용법·T5 인계](ultraino_t4_result.md). 전체 테스트 171개 통과·3개 skip. 원본 Java 반복 계산의 최대 공통 위상 정렬 오차 2.05e−7, Creo256채널 36건의 CPU/C++/실제 Taichi CUDA 및 Torch CPU 전환 비교를 확인했다. 음압 균일도와 실물 부양을 구분한다.

의존: T2, T3 진단. hologram.py와 PhaseEngine을 연결하고 hologram_ui.py를 기존 메인 창에서 사용한다.

[Kinoforms.java](../../simulations/Ultraino/AcousticFieldSim/src/acousticfield3d/algorithms/Kinoforms.java)의 가상점 생성, 전방 투영, 목표 진폭·상대 위상 제약, 공액 역전파, 송신기 진폭 제약을 옮긴다. Focus → 다중 Focus → Twin/Standing Wave 순서로 구현한다. 원본 가상점 간격·트랩 방향은 Ultraino 좌표계 변환 후 적용한다. 가상점의 영 복소값과 송신기 영 진폭 정규화를 처리한다. 측정 송신기 이득과 조절 가능한 구동 진폭을 구분하고 보드 능력에 맞는 phase-only 모드를 사용한다. 배열/목표점 변경 시 전파 행렬 캐시를 무효화한다.

완료 기준: 고정된 작은 입력과 초기 위상으로 원본/CPU 기준을 비교, 공통 위상 차이를 제거한 복소 음장 오차 확인, 목표점 균일도 및 물리 진단 비교, 반복 수·잔차·256채널 실행 시간 기록. 다중 음압 초점만으로 다중 부양 성공을 선언하지 않는다. 1~2 ms 목표는 측정 전 완료 기준으로 확정하지 않는다. Vortex/BFGS/DivTrans는 후속 과제이며 초기 부양·이송·고정 흐름의 선행조건으로 만들지 않는다.

### T5 실제 뱅크 연결에 맞는 통신과 캘리브레이션

상태: **소프트웨어 구현 및 fake-serial/Qt 검증 완료**. [상세 결과·사용법·T6 인계](ultraino_t5_result.md). 전체 테스트 208개 통과·3개 skip. 4프로파일×일반/1채널/전체 OFF 12건의 송신/내보내기 일치, 맵·보정·활성·반올림·부분 쓰기/timeout 및 상태 복원을 확인했다. 실제 펌웨어 식별·배선·파형/OFF·지속 갱신률의 측정은 미완료다.

의존: T0, T1. 보정 데이터와 프로토콜의 소프트웨어 준비는 T2~T4 진행 중 별도 작업 단위로 가능하다. 실제 송신은 사용자 요청 하드웨어 작업에서 수행한다.

기존 BoardProfile·set_channel_map·프레임 테스트를 확장한다. 입력 [channel_map.csv](../구상도/outputs/panel_8faces_32ch_R1/channel_map.csv)와 후보 맵을 읽되 실물에서 검증된 것으로 표시하지 않는다. PCB당 A/B 뱅크가 있고 DATA 4선, SHIFT/LATCH/ARM은 뱅크별 외부 연결이 필요하다. **8기판은 8개 FPGA 주소를 뜻하지 않으며, 16뱅크도 16개 체인 보드를 뜻하지 않는다.** 실제 컨트롤러 개수·펌웨어·DATA 할당·시프트 비트 방향을 확인한 뒤 프로파일을 선택한다.

Ultraino [ChainedFPGA.java](../../simulations/Ultraino/AcousticFieldSim/src/acousticfield3d/protocols/ChainedFPGA.java)는 상위 SimpleFPGA의 기본 256채널 단위로 분할하며 커밋은 호출 컨트롤러가 수행한다. 기존 AcousticStudio 태그형은 128채널씩 분할한다. 이를 PCB당 32채널만 보고 수정하지 않는다. 먼저 실제 펌웨어의 프레임 규약을 확정한다.

1채널 구동/나머지 OFF, 전체 OFF, 위상 오프셋 저장·적용, 보정 이력, 연결 해제/부분 쓰기/쓰기 timeout을 구현한다. 위상 0과 OFF를 구분한다. Python round, NumPy round, C++/Java round의 반 스텝 경계 차이를 펌웨어 기준으로 정합화한다. 초기에는 수동 위상 보정 UI를 제공하고 [AssignTransducers.java](../../simulations/Ultraino/AcousticFieldSim/src/acousticfield3d/gui/AssignTransducers.java)의 수신기 자동 채널 식별은 측정 장치가 준비되면 연결한다.

완료 기준: 맵 순열/활성 상태/보정 부호/위상 경계/커밋 바이트/부분 쓰기/연결 실패의 fake-serial 검증. 선택 프로파일 기준으로 내보낸 프레임과 송신 프레임의 바이트 일치. 실제 보드 단계에는 펌웨어 식별·배선표·채널별 파형·출력 OFF·지속 갱신률의 측정 기록이 필요하다.

### T6 단면 조작과 궤적 이송

상태: **소프트웨어 구현 및 Qt/fake-serial 검증 완료**. [T6 사용법·검증·T7 인계](ultraino_t6_result.md).
전체248 passed/4 skipped, T6 집중20 passed. 실제 Vulkan 단면 조작과 C++/Vulkan 갱신 스트림을 확인했다.
드래그는 최신 요청으로 병합하고 재생은 이전 계산/송신 완료를 기다린다. 실제 지속 갱신률·부양/이송은 미검증이다.

의존: T1, T4 및 T5 소프트웨어 경로. 기존 자동 계산·실시간 전송과 widgets.py의 이벤트 필터를 확장한다.

[TrapsPanel.java](../../simulations/Ultraino/AcousticFieldSim/src/acousticfield3d/gui/panels/TrapsPanel.java)와 [MovePanel.java](../../simulations/Ultraino/AcousticFieldSim/src/acousticfield3d/gui/panels/MovePanel.java)의 단면 클릭/드래그, 선택 입자/전체 입자 XYZ 이동을 Qt로 연결한다. 현재 CAD의 Z축을 터널 이송 축으로 사용한다. 작업 큐에 요청 번호를 부여하여 오래된 계산 결과를 버리고 GUI/VTK는 GUI 스레드에서 갱신한다. 프레임 계산/송신과 음장 그래프 갱신 속도를 분리하며 드래그 해제 시 최종 위치를 반영한다.

완료 기준: 픽킹 평면과 세계 좌표 일치, 단일/전체 이동, 취소·창 닫기·연결 실패, 렌더링과 송신의 중복 호출 방지. 230400 baud 8N1에서 258 bytes는 선로 전송만 약 11.2 ms이므로 1 ms 송신을 약속하지 않는다. 초기 30~60 Hz 범위에서 계산·송신 지연과 누락을 측정한 뒤 실제 가능한 속도를 정한다.

### T7 실제 터널의 부양 이송 고정 검증

의존: T3~T6. 사용자가 요청한 하드웨어 실험 단계에서 수행한다.

단일 입자 부양 → Z축 이송 → 검사 위치 정지·유지 → 다중 입자 순서로 검증한다. 대상의 크기·질량·물성, 배열 및 보정 해시, 구동 조건, 위치 오차, 유지 시간, 반복 횟수, 탈락 횟수, 송신 지연을 기록한다. 실패 시 실패 조건과 마지막 명령을 기록한다. 랑주뱅과의 위상/주파수 동기 및 음압 모델은 별도 검증하며 UI의 진폭 20.0 가중치를 실측 부양력으로 취급하지 않는다.

이식 초기 목표는 부양·축 방향 이송·고정이다. 회전 스캔과 영상 검사 시스템은 기존 [검사 소프트웨어 요구사항](software_requirements.md)의 별도 장기 범위로 유지한다. 작은 입자 모델을 실제 비구형 검사 부품에 그대로 적용하지 않는다.

## 다른 에이전트에게 전달할 작업 형식

한 번에 맡기는 기본 단위는 T0, T1 등이다. 동시에 작업하는 경우 공통 데이터 계약을 먼저 확정하고 app.py/phase_engine.py/hardware.py의 최종 통합 담당을 정한다. 같은 파일을 여러 에이전트가 독립 수정하는 방식은 피한다. 이 문서는 작업 분배 지침이며 이번 정리에서 별도 에이전트를 실행하지 않았다.

```text
작업 ID: T0 또는 해당 단계
기준: AGENTS.md와 docs/ultraino_migration_plan.md
하드웨어: Creo R2 8면 × 8 PCB × PCB당 32 TX = 256채널
형상: 기존 array_positions_256.json, Z축 터널, 내향 법선
수정 파일: 담당 단계에 명시된 파일만 우선 수정
재사용: 기존 계산 진입점, BoardProfile, 이벤트 필터, 저장 및 테스트
선행 결과: 완료된 단계와 검증 결과 파일/명령
완료 조건: 해당 단계의 완료 기준과 실제 실행 증거
보고: 변경 내용, 통과/실패한 검사, 미실행 항목, 남은 입력
```

현재 미확정 입력은 실제 컨트롤러/펌웨어/헤더 배선, 소자의 유효 음향 개구와 음압 보정, 실제 입자 물성이다. 이 입력을 가정한 실물 완료 판정은 금지한다. 완료한 T0~T6 소프트웨어 및 fake-serial 경로를 재사용하고 사용자 요청 하드웨어 작업에서 실제 조건을 확인한다.

## 이번 정리의 검증 범위

- 8면 × 32개 좌표·법선·ID·후보 채널 맵, Creo 행렬 및 저장 후 재조회 기록을 비교했다.
- 현재 네이티브 모델 13개와 원본 PCB의 해시를 기존 기록과 비교했다. CAD를 재생성하지 않았다.
- 기존 Python 환경 4개를 설치 메타데이터로 비교하고 앱 의존성 10개를 import했다. 추가 설치·환경 생성·GPU/solver 실행은 하지 않았다.
- 문서 8개의 UTF-8, 상대 링크 75개와 git diff --check를 확인했다. 깨진 링크는 0개이며 점검 스크립트 AST 문법도 통과했다. 앱 실행, 기존 기능 테스트, 실제 보드 송신과 부양 실험은 이번 정리 범위에 포함하지 않는다.
- 이식 시 [Ultraino LICENSE](../../simulations/Ultraino/LICENSE)의 저작권 및 MIT 고지를 보존한다.

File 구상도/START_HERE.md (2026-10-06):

# 작업 자료 — 여기서 시작

모델을 열거나 제작업체에 보낼 자료를 찾을 때 아래 표를 사용하세요.

2026-10-07 현재 기준은 **8면·8기판·기판당 32송신기, 총 256채널**입니다. PCB R1과 프레임을 포함한 Creo R2를 사용합니다. 이전 16채널 기판 두 장을 한 면에 배치한 모델은 과거 설계로 보존합니다. 소프트웨어에 형상을 반영할 때는 [Ultraino 이식 작업 계획](../docs/ultraino_migration_plan.md)을 따릅니다.

| 할 일 | 파일 또는 폴더 |
|---|---|
| 현재 8면·8기판 Creo 조립품 열기 | [tunnel8_32_r2.asm](outputs/panel_8faces_32ch_R1/mechanical/creo32_frame_R2/native/tunnel8_32_r2.asm) |
| 현재 Creo R2 치수와 사용법 | [R2 사용안내](outputs/panel_8faces_32ch_R1/mechanical/creo32_frame_R2/사용안내.md) |
| 현재 32채널 PCB와 제작 자료 | [32채널 PCB R1 안내](outputs/panel_8faces_32ch_R1/README.md) |
| 현재 256개 방사면 좌표와 법선 | [array_positions_256.json](outputs/panel_8faces_32ch_R1/array_positions_256.json) |
| 이전 8면·16기판 Creo 조립품 | [tunnel_8f_dual.asm](creo_tunnel/v2_dual_panel/native/tunnel_8f_dual.asm) |
| 이전 6면 Creo 조립품 | [tunnel_6f_v2.asm](creo_tunnel/v2_dual_panel/native/tunnel_6f_v2.asm) |
| 이전 Creo 버전과 사용법 | [이전 Creo 안내](creo_tunnel/README.md) |
| 이전 8면·16기판 업체 제출 자료 | [이전 PCB 안내](outputs/pcb/README.md) |
| KiCad 원본 수정 — 6면용 | [6면 기판](outputs/pcb/polygon_panels/panel_6faces_16ch/) |
| KiCad 원본 수정 — 8면용 | [8면 기판](outputs/pcb/polygon_panels/panel_8faces_16ch/) |
| 초기 6면·8면 예산 확인 | [제조 및 추가 부품 견적](outputs/pcb/polygon_panels/제작및추가부품견적_센서제외.md) |
| 생성 스크립트 찾기 | [scratch 안내](scratch/README.md) |

## 구성과 수량 구분

- `outputs/panel_8faces_32ch_R1`: 현재 PCB. 한 장 4열×8행·32송신기, 8면에 한 장씩 총 8기판·256송신기. 현재 Creo는 하위 `mechanical/creo32_frame_R2`입니다.
- `creo_tunnel/v1_single_panel`: 초기안. 6면 6기판·96송신기, 8면 8기판·128송신기.
- `creo_tunnel/v2_dual_panel`: 이전 모델. 8면은 면당 16채널 기판 두 장, 총 16기판·256송신기입니다. 현재 32채널 기판 한 장 구조와 구분합니다.
- 기존 `6면_8면` 및 16기판 견적은 이전 구성 기준이며 현재 32채널 기판 8장의 총예산으로 그대로 사용하지 마세요.
- `ver1`~`ver4`: 기존 사용자 모델. 이번 정리에서 이동하거나 변경하지 않았습니다.

## 폴더 지도

```text
creo_tunnel/                 이전 Creo 모델과 사용 안내
  v2_dual_panel/             이전 16기판 구성
  v1_single_panel/           초기안
outputs/
  panel_8faces_32ch_R1/      현재 32채널 PCB 및 8기판 Creo R2
  pcb/                      KiCad, Gerber, BOM·PnP, 초기 견적 문서
  cad_generation/           Creo 생성 원본·중간 결과·기존 배포 ZIP
  budgets/                  예산표
  vendor_templates/         업체 원본 양식
  reference_analysis/       SonicSurface 참고 설계 분석
  concepts/                 초기 개념도
  docs/                     도구 설치 기록
scratch/                    생성·검증 스크립트와 임시 자료
ver1/ ~ ver4/               기존 사용자 모델
```

Creo는 선택한 버전의 `native` 폴더를 작업 디렉터리로 지정하고 조립품을 여세요. ASM과 참조 PRT를 개별적으로 옮기지 마세요. 현재 대상은 `outputs/panel_8faces_32ch_R1/mechanical/creo32_frame_R2/native`입니다. `creo_tunnel`과 `outputs/cad_generation`에는 이전 모델과 생성 기록을 보존합니다.

PCB 자료는 견적용 P0입니다. 이번 폴더 정리는 제작 승인이나 부양 성능 검증을 의미하지 않습니다.

## 2026-10-06 정리 기록

기존 파일을 삭제하지 않고 용도별로 이동했습니다. 모델·Gerber·CSV·XLSX·ZIP 내용은 보존하고 스크립트 경로와 일부 안내 문서만 수정했습니다. [이동 및 SHA-256 확인 기록](scratch/organization/organization_verification_20261006.json)을 참고하세요.

기존 ZIP, JSON 생성 기록 및 manifest는 생성 당시 자료이므로 이전 경로나 수정 전 문서 해시가 들어 있을 수 있습니다. 현재 위치는 이 안내와 이동 기록을 기준으로 찾으세요.

`scratch/creo_cad_env`와 `scratch/pcba_artifact`의 실행 환경은 경로 의존성을 고려해 제자리에 보존했습니다. CAD 생성과 업체 업로드는 이번 작업에서 실행하지 않았습니다.

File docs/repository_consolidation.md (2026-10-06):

# 2026-10-07 저장소 통합

최종 GitHub 저장소와 로컬 작업 폴더는 `AcousticStudio`입니다. 내부 파일의 기준은 ver2의 커밋 `719ebd00a79faf92653e92bea007ed420f6375ff`입니다. 이 커밋은 ver2의 기존 GitHub 커밋 `2417356`에 클래식/모던 UI 선택, DOILLABS 업로드 자료 수정, 구상도 재정리와 관련 로컬 작업을 포함합니다.

기존 저장소의 마지막 커밋 `197962c`와 ver2 이력을 병합 커밋의 두 부모로 보존합니다. 파일을 복사하여 이력을 새로 시작하거나 기존 main을 강제로 교체하는 방식은 사용하지 않습니다. 파일 트리는 ver2를 기준으로 하며 이 README와 통합 기록만 추가 정리했습니다.

## 포함된 작업

- 초음파 위상 계산, 음장/궤적 제어, k-Wave, 보드 통신 코드와 기존 진행 문서.
- 보기 → UI → 클래식/모던 전환, 마지막 선택 저장, 공통 보드 메뉴.
- 구상도 전체 추적 자료: 초기/최신 PCB, Gerber, BOM/PnP, DOILLABS 원본 템플릿 및 업로드 수정본, 부품 조사, 회로 검토 자료.
- 32채널 PCB R1 및 8면 256채널 배치, Creo 모델과 외부 프레임 R2, 미리보기, 생성/검증 기록.
- 구상도 폴더 재정리, 시작 안내, 작업 스크립트 및 요청에 따라 만든 UI 수정 전 백업.

ver2의 추적 파일 전체를 대조하고, CAD/제작 산출물 및 UI 백업은 실제 바이트와 SHA-256 보존을 확인합니다. 계산 코드·통신 코드는 원본과 비교했고, Qt 전환 및 보드 프레임 검사와 실제 앱 offscreen 전환 경로를 확인합니다. 자동 검사 결과는 실제 보드·부양 성능 검증을 뜻하지 않습니다.

가상환경, node_modules, PTC 런타임, 세션 로그, 캐시 등 기존 Git 제외 항목은 GitHub 배포에 포함하지 않습니다. 해당 로컬 자료와 원래 `AcousticStudio_ver2` 폴더 및 GitHub 저장소는 보존합니다. 이후 신규 작업과 푸시는 `AcousticStudio`에서 진행합니다. ver2 원격 저장소 삭제나 이름 변경은 수행하지 않습니다.

통합 시점의 원래 main은 로컬 `archive/pre-consolidation-20261007` 브랜치로도 보존했습니다. 파일 대조 결과는 [검증 JSON](repository_consolidation_validation.json)에 기록합니다.

기존에 추적된 Creo 세션 로그 2개는 ver2 로컬 원본 바이트를 그대로 보존했습니다. 과거 Git 저장본과의 차이는 CRLF/LF 줄바꿈뿐입니다. UI 백업의 소스·자산 18개는 해시로 검증했으며 자동 생성 Python 캐시 9개는 배포에서 제외했습니다. 원래 캐시 포함 백업은 ver2 폴더에 보존되어 있습니다.

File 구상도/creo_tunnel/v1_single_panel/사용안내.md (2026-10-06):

# 초음파 부양 터널: Creo 9 모델

Creo Parametric 9.0.12.0에서 저장한 네이티브 부품(PRT) 및 조립품(ASM)입니다. 길이 단위는 mm이며 Creo의 mmNs 단위계를 사용했습니다.

## 모델과 치수

| 항목 | 6면 | 8면 |
|---|---:|---:|
| PCB 부품 | `6faces/native/pcb_6f.prt` | `8faces/native/pcb_8f.prt` |
| 최상위 조립품 | `6faces/native/tunnel_6faces.asm` | `8faces/native/tunnel_8faces.asm` |
| PCB 폭 × 길이 × 두께 | 60 × 180 × 1.6 mm | 48 × 180 × 1.6 mm |
| 동일 PCB의 조립 개수 | 6 | 8 |
| PCB당 트랜스듀서 | 2열 × 8행 = 16개 | 2열 × 8행 = 16개 |
| 트랜스듀서 총수 | 96개 | 128개 |
| 마주 보는 방사면 사이 거리 | 150 mm | 150 mm |
| 터널 높이 | 180 mm | 180 mm |
| 전체 외곽 크기 X × Y × Z | 약 205 × 236.714 × 180 mm | 205 × 205 × 180 mm |

PCB 외곽, 두께, 트랜스듀서 위치와 51개의 관통 구멍은 기존 KiCad 설계에서 추출했습니다. 원본은 원래 자료조사 작업 폴더의 `outputs/pcb/polygon_panels/panel_6faces_16ch/panel_6faces_16ch.kicad_pcb`와 8면에 대응하는 파일입니다. 이 저장소에 포함된 좌표 추출본은 `pcb_geometry.json`입니다. 추출 좌표는 `pcb_geometry.json`에서 확인할 수 있습니다.

PCB 사이에 공간을 남기도록 각 면 중앙에 좁은 패널을 배치했습니다. 전체 측면을 덮는 판이 아닙니다. 트랜스듀서는 중심을 향하고 있습니다. 150 mm의 방사면 간 거리와 트랜스듀서 높이 12.5 mm는 개념 모델에 사용한 값이며, 실물 구매 부품의 도면 및 음향 실험에 따라 조정해야 합니다.

## Creo에서 열기

1. ZIP을 사용할 경우 폴더 구조를 유지하며 모두 압축 해제합니다.
2. Creo의 **File → Manage Session → Select Working Directory**에서 원하는 `6faces/native` 또는 `8faces/native` 폴더를 선택합니다.
3. **File → Open**으로 `tunnel_6faces.asm` 또는 `tunnel_8faces.asm`을 엽니다.
4. PCB만 보려면 같은 폴더의 `pcb_6f.prt` 또는 `pcb_8f.prt`를 엽니다.
5. **File → Prepare → Model Properties → Units**에서 mmNs를, **Analysis → Measure**에서 PCB 외곽 치수를 확인할 수 있습니다.

ASM은 다른 ASM 및 PRT를 참조하므로 최상위 ASM 하나만 별도 폴더로 이동하면 안 됩니다. 같은 `native` 폴더 안의 모든 부품과 하위 조립품을 함께 보관하십시오. Creo에서 다시 저장할 때 파일명 뒤에 `.1`, `.2` 등의 버전 번호가 생기는 것은 정상입니다.

## 조립 구조

최상위 `tunnel_*faces.asm` 아래에 가져오기 과정에서 생성된 `tunnel_*faces_1.asm`이 있습니다. 그 아래에는 각 면의 `panel_*f_01.asm`부터 6개 또는 8개의 패널 조립품, 상하 프레임 링이 있습니다. 각 패널은 PCB 1개와 동일한 트랜스듀서 부품 16개를 참조합니다. 상하 링 역시 동일한 부품을 서로 다른 높이에 배치했습니다. `lower`라는 링 파일명은 공유 부품의 이름이며 상단 링이 빠진 것이 아닙니다.

## 모델의 범위와 수정

이 파일은 STEP의 솔리드 형상을 Creo로 가져와 실제 네이티브 PRT/ASM으로 저장했습니다. PCB, 트랜스듀서, 프레임은 서로 분리된 부품이며 조립 위치를 유지합니다. 다만 원래 스케치·돌출의 치수 기반 피처 이력은 포함하지 않습니다. 직접 치수값을 바꿔 재생성하는 완전한 파라메트릭 설계와는 구분해야 합니다. 해당 피처 이력이 필요하면 현재 형상을 기준으로 Creo에서 스케치·돌출·구멍·패턴 피처를 구성해야 합니다.

트랜스듀서는 지름 16 mm, 높이 12.5 mm의 단순 외형입니다. 리드 핀, 전면 망, PCB의 동박과 회로 부품, 배선, 커넥터는 포함하지 않았습니다. 프레임 링 높이는 8 mm이고 PCB 자리에는 각 방향으로 0.3 mm의 여유를 주었습니다. 나사·브래킷·케이블 공간 및 실제 고정 방법은 확정되지 않은 개념 구조입니다. 이 형상 확인만으로 부양 성능이나 제작 승인까지 검증된 것은 아닙니다.

## 검증 파일

- `native_generation_report.json`: Creo 9의 저장 결과 및 각 모델 단위계.
- `native_reopen_report.json`: 전달용 네이티브 파일을 새 Creo 세션에서 열어 확인한 결과.
- 각 `geometry_checks.json`: PCB 치수, 개수, STEP 재읽기, 단순화한 솔리드 간 간섭 검사.
- 각 `tunnel_*faces_preview.png`: 실제 STEP 형상을 렌더링한 미리보기. Creo 화면 캡처는 아닙니다.

PCB와 프레임 등 모델에 포함된 솔리드끼리의 체적 겹침을 검사했습니다. 모델에서 생략한 부품, 핀과 배선에 대한 간섭까지 확인한 결과는 아닙니다.

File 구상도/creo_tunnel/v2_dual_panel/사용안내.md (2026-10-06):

# 공통 부품을 반복 참조하는 Creo 터널 모델 V2

## 변경 내용

기존 모델을 덮어쓰지 않고 별도 폴더에 생성했습니다. 같은 형상의 트랜스듀서, PCB, 링, 패널 조립품은 공통 파일을 반복 참조합니다. 면마다 별도의 패널 ASM을 만들지 않습니다. 6면 모델은 배치와 치수를 유지하며 참조 구조를 간소화했습니다. 8면 모델은 각 면에 기존 48×180×1.6 mm PCB 두 장을 나란히 배치하고 가운데에 촬영용 20 mm 틈을 둡니다.

| 항목 | 6면 | 새 8면 |
|---|---:|---:|
| PCB 치수 | 60×180×1.6 mm | 48×180×1.6 mm |
| PCB 장수 | 6 | 16 |
| PCB당 트랜스듀서 | 16 | 16 |
| 전체 트랜스듀서 | 96 | 256 |
| 각 면의 두 PCB 사이 틈 | 해당 없음 | 20 mm |
| 면당 PCB 두 장과 틈의 전체 폭 | 60 mm | 116 mm |
| 면 간 회전각 | 60° | 45° |
| 마주 보는 초음파 방사면 간 거리 | 150 mm | 300 mm |
| PCB 전면까지의 중심 거리 | 87.5 mm | 162.5 mm |
| PCB 전면 위치에서 정다각형 한 변 길이 | 약 101.036 mm | 약 134.619 mm |
| 전체 외곽 X×Y×Z | 약 205×236.714×180 mm | 355×355×180 mm |

새 8면에서 한 면의 패널 묶음 폭은 48+20+48=116 mm입니다. PCB 전면 위치의 정팔각형 한 변은 약 134.619 mm이므로 묶음 양끝에 각각 약 9.31 mm를 남깁니다. 각 면에 같은 묶음을 45°씩 회전해 배치했습니다. 기준 정팔각형과 프레임은 정팔각형을 유지하며, 면의 중간에 의도적으로 열린 공간이 있습니다.

상하 링은 각각 8 mm 높이입니다. PCB 사이의 중앙 틈은 링 사이에서 높이 164 mm 구간이 열려 있습니다. 카메라 자체나 렌즈는 포함하지 않았으며 촬영 화각, 거리, 3D 스캔 품질은 확인하지 않았습니다.

## 파일 구조

두 최상위 ASM과 공통 부품을 모두 `native` 폴더에 보관합니다. 네이티브 파일 종류는 총 10개입니다.

```text
tunnel_6f_v2.asm
├─ panel_6f.asm × 6
│  ├─ pcb_6f.prt × 1
│  └─ tx16.prt × 16
└─ ring_6f.prt × 2

tunnel_8f_dual.asm
├─ facepair_8f.asm × 8
│  └─ panel_8f.asm × 2
│     ├─ pcb_8f.prt × 1
│     └─ tx16.prt × 16
└─ ring_8f.prt × 2
```

6면만 별도로 전달할 때 필요한 파일은 5개이며, 새 8면만 전달할 때는 6개입니다. 두 모델은 동일한 `tx16.prt`를 공유합니다. 이름 뒤 숫자가 달린 면별 패널 ASM이나 불필요한 최상위 래퍼 ASM은 없습니다.

## Creo 9.0.12.0에서 열기

1. ZIP을 전체 압축 해제합니다.
2. Creo에서 작업 폴더를 `native`로 지정합니다.
3. `tunnel_8f_dual.asm`을 엽니다. 6면은 `tunnel_6f_v2.asm`입니다.
4. 한 면의 두 PCB와 틈만 확인하려면 `facepair_8f.asm`을 엽니다. PCB 한 장과 트랜스듀서만 확인하려면 `panel_8f.asm`을 엽니다.
5. 모델 트리에서 동일한 ASM/PRT 이름이 반복되는지 확인합니다. 공통 부품을 수정하고 조립품을 재생성하면 해당 부품을 참조하는 인스턴스 전체에 변경이 반영됩니다.
6. Model Properties의 Units에서 mmNs, Measure에서 PCB 폭 48 mm, 길이 180 mm, 두께 1.6 mm 및 두 PCB 모서리 사이 거리 20 mm를 확인합니다.

파일을 옮길 때는 `native` 폴더 전체를 함께 이동하십시오. Creo의 저장 버전 번호 `.1`, `.2`는 정상이며 제공 파일은 최신 저장 내용으로 정리했습니다.

## 설계 범위와 검증

PCB는 기존 KiCad 설계에서 추출한 동일한 외곽과 관통 구멍을 사용합니다. 트랜스듀서는 Ø16×12.5 mm의 외형 솔리드입니다. PCB와 트랜스듀서의 형상 피처는 가져온 솔리드이며 스케치·돌출 이력은 없습니다. 새 ASM들은 Creo에서 직접 공통 모델을 조립하고 Fix 구속을 적용했습니다. 새로운 치수와 간격에 연동되는 파라메트릭 조립 관계식이나 원형 패턴 피처까지 구성한 것은 아닙니다.

나사와 브래킷, 회로 부품 외형, 트랜스듀서 핀 및 배선은 생략했습니다. 링의 PCB 슬롯은 각 방향으로 0.3 mm의 조립 여유를 갖지만 실제 고정 방법과 공차는 확정되지 않았습니다.

`geometry/checks_*f.json`은 입력 치수, 배치 행렬, 솔리드 개수 및 체적 간섭 검사 결과입니다. `native_build_report.json`과 `native_reopen_report.json`은 Creo의 생성 결과와 전달용 파일을 새 세션에서 다시 읽은 결과입니다. 미리보기 PNG는 STEP 형상을 렌더링한 것으로 Creo 화면 캡처는 아닙니다.

기하 배치와 공유 참조 구조에 대한 검증입니다. 8면의 방사면 간 거리를 150 mm에서 300 mm로 넓혔으므로 이 모델의 부양 성능은 새 간격과 256채널 좌표로 시뮬레이션하고 실험해야 합니다. 기존 좁은 터널과 동일한 부양력을 갖는다고 가정할 수 없습니다.

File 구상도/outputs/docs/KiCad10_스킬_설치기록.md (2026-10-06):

# KiCad 10 설계 지원 스킬 설치 기록

## 2026-10-06 현재 계정 설치

사용자가 KiCad 10.0 회로도 설계 스킬 다운로드를 요청하여 현재 계정에 아래 두 스킬을 설치했다. 아래의 2026-10-04 기록은 다른 계정의 설치 이력이며 현재 설치 위치와 구분한다.

- 설치 루트: `C:\Users\line0\AppData\Roaming\orca\codex-accounts\a053bc42-2712-4a29-83e3-7bca6d3b0d3f\home\skills`.
- `kicad-schematic`: American-Embedded/kistack의 `skills/schematic`, 커밋 `8494dbde095669df081950cbb6b24d08a21e25b0`. 회로도 작성·수정, 이미지 검토와 넷리스트 검증 지침. 특정 KiCad 버전 전용 코드는 아니며 현재 KiCad 10.0.6 CLI로 적용한다.
- `kicad`: aklofas/kicad-happy의 `skills/kicad`, 커밋 `78b8f02e70af5a29aef99ebd66b0d3538fb6010c`. 스킬 설명에 KiCad 5~10 지원 명시. 회로도·PCB·넷리스트 분석 및 교차 검토 도구 포함.
- Skills CLI 검색 설치 수: 회로도 스킬 312, kicad 893. GitHub 조회 stars: 각각 395, 1,336. 조회 시점 값이며 품질이나 전체 호환성 보증은 아니다.
- 공식 skill-installer의 GitHub 설치 스크립트로 커밋을 고정하여 다운로드. 설치된 SKILL.md 및 분석 스크립트 존재 확인.
- 실제 KiCad CLI: `C:\Program Files\KiCad\10.0\bin\kicad-cli.exe`, 버전 10.0.6.
- 검증: `analyze_schematic.py --help` 정상 종료, 기존 KiCad 10.0.6 회로도 `panel_8faces_16ch.kicad_sch`를 분석기에 입력해 JSON 출력 정상 완료. 결과는 `pcb_review_2026-10-06/skill_install_schematic_smoke.json`에 저장.
- 이 실행은 설치 및 파일 파싱 확인이며 새 회로 설계·전체 설계 리뷰·전기적 타당성 검증이 아니다. 기존 회로도/PCB는 변경하지 않았다.
- 두 스킬은 KiCad 내부 플러그인이 아니라 Codex가 사용하는 설계 지원 스킬이다. 다음 대화 턴부터 사용 가능하다.

출처: [회로도 작성 스킬](https://github.com/American-Embedded/kistack/blob/8494dbde095669df081950cbb6b24d08a21e25b0/skills/schematic/SKILL.md), [KiCad 5~10 분석 스킬](https://github.com/aklofas/kicad-happy/blob/78b8f02e70af5a29aef99ebd66b0d3538fb6010c/skills/kicad/SKILL.md).

---

확인일: 2026-10-04

## 현재 환경

- Windows / PowerShell.
- 실제 확인한 KiCad CLI 버전: 10.0.6.
- 실행 파일: `C:\Users\line0\AppData\Local\Programs\KiCad\bin\kicad-cli.exe`.
- 설치 위치: `C:\Users\line0\AppData\Roaming\orca\codex-accounts\3085b31c-8e42-4e8c-be20-346bf798bd11\home\skills`.
- 기존 스킬 목록에는 KiCad 전용 스킬이 없었다.

## 설치한 스킬

| 설치 이름 | 출처 | 용도 | 설치 기준 커밋 |
|---|---|---|---|
| kicad-schematic | american-embedded/kistack, skills/schematic | 회로도 작성·수정, 데이터시트와 넷리스트 대조, 도면 시각 검토 | 8494dbde095669df081950cbb6b24d08a21e25b0 |
| kicad-pcb | american-embedded/kistack, skills/pcb | 부품 배치, DRC, 레이어 및 3D 간섭 검토 | 8494dbde095669df081950cbb6b24d08a21e25b0 |
| kicad | aklofas/kicad-happy, skills/kicad | 회로도·PCB·Gerber 분석 및 회로도와 PCB 비교 | a6bba1add1e18b89e3aa0824b9769ed1d9d79174 |

KiStack은 KiCad 10 전용 구현이나 GUI 조작 플러그인이 아니라 설계 작업 지침이다. 현재 설치된 KiCad 10.0.6의 CLI와 라이브러리를 사용해 적용한다. kicad-happy는 스킬 설명에서 KiCad 5~10 지원을 명시한다. 모두 커뮤니티 제작 스킬이며 KiCad 공식 제공 스킬은 아니다.

## 선택 근거

skills.sh 및 GitHub에서 공개 후보를 검색하고 스킬 원문과 저장소 정보를 비교했다. 조회 당시 KiStack 저장소는 395 stars, kicad-happy는 1,330 stars였다. Skills CLI 조회 설치 수는 KiStack 회로도 309, PCB 307, kicad-happy의 kicad 888이었다. 수치는 조회 시점의 값이며 품질 보증이 아니다.

- KiStack: 별도 MCP 서버나 WSL 없이 기존 도구를 사용해 설계할 수 있는 지침. 회로도와 PCB 작업을 분리해 필요한 지침을 선택할 수 있다.
- kicad-happy: 원본 파일과 분석 결과의 교차 검증, 근거 및 확신 수준 구분을 강조하며 분석 스크립트를 제공한다.
- Potapovrg/kicad-skill: KiCad 10을 명시하지만 WSL과 작성자의 경로를 전제로 하므로 이번 Windows 환경의 기본 선택에서 제외.
- bretbouchard/kicad-agent: 별도 volta 백엔드와 Beads 작업 추적 도구 의존성이 있어 제외.
- fl4p/kicad-design: 상세 검증 지침이 있으나 추가 외부 도구와 작성자의 로컬 환경을 참조하는 부분이 있어 기본 선택에서 제외.
- Seahan1/kicad-agent: 회로도 절차는 관련성이 있으나 확인 당시 사용 근거가 상대적으로 적어 기본 선택에서 제외.

## 설치 및 확인 범위

- skill-installer의 GitHub 설치 스크립트로 커밋을 고정해 세 스킬 설치 완료.
- `analyze_schematic.py --help`, `analyze_pcb.py --help`가 Python 3.13.9에서 오류 없이 종료됨을 확인.
- 이는 도구 시작과 기본 의존성 확인이다. 실제 설계 전체 분석, 모든 기능의 KiCad 10 호환성, 회로의 전기적 타당성 또는 부상 성능을 검증한 것은 아니다.
- 전체 설계 검토를 시작할 때 해당 스킬의 전체 지침을 다시 읽고, EMC·SPICE·데이터시트 분석 등 관련 보조 스킬이 필요한지 확인한다. 이번 설치에는 해당 보조 스킬을 포함하지 않았다.
- KiCad 애플리케이션 내부 메뉴에 설치되는 플러그인이 아니라 AI 에이전트가 읽는 스킬이다. 다음 대화 턴부터 사용 가능하다.
- 기존 회로도와 PCB 파일은 수정하지 않았다.

## 다음 설계 단계

사용자는 기존 6면·8면 초안의 구조가 원하는 방향과 다르다고 밝혔다. 해당 초안의 패널 치수, 열·행 수, 부품 위치를 확정 조건으로 취급하지 않는다. 기판 수정 전에 사용자와 전체 형상, 트랜스듀서 배열, 구동 회로의 위치, 패널별 인터페이스를 토론해 구체화한다.

## 출처

- [KiStack](https://github.com/american-embedded/kistack)
- [KiStack 회로도 스킬](https://github.com/american-embedded/kistack/blob/8494dbde095669df081950cbb6b24d08a21e25b0/skills/schematic/SKILL.md)
- [KiStack PCB 스킬](https://github.com/american-embedded/kistack/blob/8494dbde095669df081950cbb6b24d08a21e25b0/skills/pcb/SKILL.md)
- [kicad-happy](https://github.com/aklofas/kicad-happy)
- [kicad-happy 분석 스킬](https://github.com/aklofas/kicad-happy/blob/a6bba1add1e18b89e3aa0824b9769ed1d9d79174/skills/kicad/SKILL.md)
- [KiCad 10 CLI 공식 문서](https://docs.kicad.org/10.0/en/cli/cli.html)

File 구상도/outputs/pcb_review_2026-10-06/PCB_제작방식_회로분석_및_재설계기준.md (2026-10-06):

# 기존 PCB 제작 방식·회로 분석 및 후속 설계 기준

분석일: 2026-10-06. 대상은 AcousticStudio_ver2의 `구상도`에 보관된 KiCad P0 패널, 조립 견적 패키지, 최신 Creo V2 및 참고 SonicSurface FPGA 소스다. 기존 설계·Gerber·BOM은 변경하지 않았다. 실물 제작·납품·작동 완료 여부를 증명하는 기록은 이번 검토에서 확인하지 않았다.

## 1. 어떤 버전을 기준으로 재설계해야 하는가

| 구분 | PCB 한 장 | 기판 수 | 송신기/독립 출력 수 | 방사면 간 거리 |
|---|---|---:|---:|---:|
| 6면 | 60×180×1.6 mm, 16채널 | 6 | 96 | 150 mm |
| 초기 8면 | 48×180×1.6 mm, 16채널 | 8 | 128 | 150 mm |
| 최신 Creo V2 8면 | 동일한 48×180×1.6 mm, 16채널 | 16 | 256 | 300 mm |

최신 8면은 면당 2장을 나란히 놓고 가운데 20 mm 틈을 둔다. 면당 32채널이지만 PCB 한 장이 32채널인 것은 아니다. 전체 외곽은 약 355×355×180 mm다. 보드당 송신기는 2열×8행, 폭 방향 중심 간격 18 mm, 길이 방향 20 mm다.

중요한 자료 차이: `polygon_panels/panel_8faces_16ch/array_positions.json`은 **128개·방사면 간 거리 150 mm의 초기 좌표**다. 최신 V2 256채널 배치 입력으로 사용할 수 없다. `creo_tunnel/v2_dual_panel` 및 `outputs/creo_tunnel_reused_v2`의 최신 기하 자료를 기준으로 좌표계·법선·PCB 번호·채널 번호를 새로 정의해야 한다. 3D 배치 행렬만으로 전기 채널 순서까지 확정되지는 않는다.

## 2. 설계·제작 방식

기존 SonicSurface의 Gerber 연결 분석과 회로 자료를 참고하여 새 KiCad 회로도와 PCB를 작성한 방식이다. 원본 기판의 단순 확대·축소가 아니다. 부품 심벌과 풋프린트를 프로젝트 내부 `Levitation.kicad_sym` 및 `Levitation.pretty`로 보관해 수정할 수 있다.

설계 파일은 `outputs/polygon_panels/panel_6faces_16ch`와 `panel_8faces_16ch`의 `.kicad_pro`, `.kicad_sch`, `.kicad_pcb`다. 현존 스크립트는 Gerber 묶음, PCB 치수 추출, BOM/PnP 생성·검증 및 Creo 구성 작업을 담당한다. 이번 검색에서는 최초 회로도·배선 전체를 재생성하는 스크립트를 확인하지 못했으므로 KiCad 원본을 수정 기준으로 삼는다.

제조 사양은 2층 FR-4, 두께 1.6 mm이며 F.Cu/B.Cu 양면에 배선과 GND 영역이 있다. 전면은 안쪽을 향하는 송신기 16개, 후면은 IC·저항·커패시터·커넥터가 배치된다. 실제 공정은 다음과 같이 구분한다.

1. PCB 제조: 동박·마스크·실크·외곽 Gerber와 드릴 파일로 기판 제작.
2. 후면 SMT: 레지스터 2개, 드라이버 8개, NPN 1개, 저항 25개, 세라믹 커패시터 19개. 총 55개/장.
3. THT 조립: 전면 송신기 16개, 후면 헤더 2개와 전해 커패시터 1개. 총 19개/장. SMT와 별도로 업체의 삽입 실장·수작업 납땜 포함 여부를 확인해야 한다.
4. 조립 검증: 뒤쪽 송신기 리드 돌출과 후면 부품 간섭, 극성, 고정홀·프레임 공차, 출력 파형 확인.

최신 8면 전체는 16장, SMT 880개, THT 304개, 합계 1,184개다. 업체 BOM 수량은 한 장 기준이고 제작 장수만 16장으로 지정한다. 전원공급기·FPGA·케이블·프레임은 패널 BOM에 포함되지 않는다.

Gerber 견적 ZIP은 `polygon_panels/gerber_quotes`, 조립 BOM/PnP와 DOILLABS 업로드 양식은 `polygon_panels/pcba_8faces_16boards`에 있다. SMT 좌표는 Bottom, mm, Gerber와 동일 원점이며 Y가 음수다. 임의로 Bottom X를 다시 반전하지 말고 업체 미리보기로 회전·원점 규칙을 확인한다.

## 3. 회로가 동작하는 원리

```text
PC의 위상 명령 → FPGA의 채널별 파형 생성
                       ↓ DATA_A / DATA_B + SHIFT / LATCH
               U1 / U2: 74HCT595, 5 V
                       ↓ IN00~IN15
               U3~U10: TC4427A, 듀얼 드라이버
                       ↓ OUT00~OUT15
               T1~T16: 송신기 한 핀 구동 / 다른 핀 GND

ARM → R17 → Q1 → 두 레지스터의 /OE 제어
외부 +5 V → 논리 / 외부 DRV_VDD → 드라이버 / GND 공통
```

### 파형 생성과 직렬 데이터

U1과 U2는 각각 별도 DATA를 받아 8출력을 만든다. 두 레지스터의 SHIFT와 LATCH는 공유하며 직렬 출력 9번 핀은 사용하지 않는다. 여러 PCB를 하나의 DATA로 길게 데이지 체인하는 회로가 아니다. 이 방식으로 6면 96채널은 DATA 12개, 초기 128채널은 16개, 최신 256채널은 **32개**가 필요하다.

74HCT595에는 주파수·위상 값을 해석하는 기능이 없다. FPGA가 각 순간의 8채널 HIGH/LOW 비트를 SHIFT로 보내고 LATCH로 동시에 갱신해야 한다. PC가 전송하는 위상 바이트와 PCB 커넥터 DATA의 파형 비트는 서로 다른 단계다.

참고 소스 `simulations/SonicSurface/Firmware/FPGA primary/src/AllChannels.vhd`에는 256개의 PhaseLine을 32개의 Mux8 직렬 출력으로 묶는 구조가 있다. `PhaseLine.vhd`는 32단계 위상 카운터를 사용한다. 40 kHz·32단계·8비트 직렬화라는 조건에서 계산한 데이터 전송률은 DATA당 10.24 Mbit/s이며, 실제 SHIFT/LATCH 간격과 클록은 BDF·PLL·보드 파형으로 확인해야 한다. 일반 GPIO로 위상 값만 한 번 보내는 방식으로는 지속 파형을 만들 수 없다.

QSF에 DATA[0..31], SHIFT_CLOCK_1/2, LATCH_CLOCK_1/2의 FPGA 칩 핀 할당이 있다. 이는 256채널 연결 후보가 있다는 의미이며, 사용 중인 코어 보드 헤더·분배 회로·ARM 할당까지 호환성이 검증됐다는 뜻은 아니다.

로컬 채널 0~7은 U1의 핀 15,1,2,3,4,5,6,7 → U3~U6 → T1~T8이고, 8~15는 U2 → U7~U10 → T9~T16이다. 직렬 비트 전송 순서와 레지스터 QA~QH의 최종 대응은 별도로 확인해야 한다. 후속 배열에서는 전역 채널, 면 번호, 면 안의 두 PCB 번호, 레지스터 DATA 번호, 물리 출력의 관계를 표로 고정한다.

### 논리 전원과 드라이버

논리 전원은 +5 V이며 HCT 계열은 TTL 입력 임계값을 갖는다. TI 자료의 HIGH 최소 2 V 조건은 정상적인 3.3 V FPGA 신호를 받는 설계 의도와 맞는다. HC형으로 자동 대체하면 입력 임계값을 다시 검토해야 한다. [TI 데이터시트](https://www.ti.com/lit/ds/symlink/sn74hct595.pdf)

TC4427A는 비반전 듀얼 MOSFET 게이트 드라이버를 송신기 구동에 사용한 것이다. 소자 전원 동작 범위는 4.5~18 V, 입력 HIGH 최소는 2.4 V다. 출력 한 개씩을 송신기에 연결하며 송신기의 다른 핀은 GND다. 브리지 회로가 없으므로 이상적인 출력은 약 0~DRV_VDD이고, 부하 양단 전압은 약 DRV_VDD Vpp다. 실제 부하 파형·링잉은 계측해야 한다. 1.5 A 표기는 피크 드라이버 능력이며 패널의 연속 소비전류가 아니다. [Microchip 데이터시트](https://ww1.microchip.com/downloads/aemDocuments/documents/APID/ProductDocuments/DataSheets/TC4426A-TC4427A-TC4428A-1.5A-Dual-High-Speed-Power-MOSFET-Drivers-2000142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)

회로에는 DC/DC, 승압기, 외부 브리지 MOSFET, 전류 계측, 과전류 차단이나 온도 계측이 없다. 입력 보호·전원 감시도 별도로 설계해야 한다. 필요한 공급 전류와 방열은 송신기 정전용량·전압·주파수와 실측으로 산정하며, 알려지지 않은 연속 구동 정격을 impulse 정격으로 대신할 수 없다.

### ARM과 초기 상태

- R19 10 kΩ은 OE_N을 +5 V로 올려 기본적으로 레지스터 출력을 비활성화한다.
- ARM HIGH → R17 10 kΩ → Q1 베이스 → Q1이 OE_N을 낮춤 → U1/U2 출력 활성화.
- R18 100 kΩ은 Q1 베이스를 접지로 당긴다. R1~R16 10 kΩ은 레지스터가 고임피던스일 때 드라이버 입력을 LOW로 유지한다.
- R20/R21 33 Ω은 SHIFT/LATCH 직렬 저항이고 R22~R25 100 kΩ은 DATA/클록 입력 풀다운이다.

ARM은 드라이버 전원을 끊는 스위치가 아니다. 전원이 정상인 조건에서 레지스터 출력과 입력 풀다운을 통해 출력을 LOW로 유도한다. /SRCLR은 +5 V에 고정돼 있어 자동 데이터 초기화가 없고, /OE 제어도 내부 데이터를 지우지 않는다. 따라서 ARM LOW → 전원 안정 → 유효한 데이터 전송·래치 → ARM HIGH 순서가 필요하다. 전원 상실, 역급전, FPGA 정지까지 차단을 보장하려면 감시 회로와 펌웨어 정책을 추가 검토해야 한다.

### 커넥터와 디커플링

J1 핀 1~10: GND, +5 V, DATA_A, GND, DATA_B, GND, SHIFT_PIN, LATCH_PIN, ARM, GND.

J2 핀 1~3: DRV_VDD, GND, +5 V. J1과 J2의 +5 V는 같은 망이다. 논리/드라이버 전압은 구분하지만 접지는 공통이다. 패널 안에 전압 변환 기능은 없다.

C1~C8은 드라이버별 100 nF, C11~C18은 드라이버별 1 µF, C19는 DRV_VDD 벌크 220 µF다. C9/C10은 레지스터별 100 nF이고 C20은 논리 전원 10 µF다. 용량뿐 아니라 부품 치수·전압·MLCC의 DC 바이어스에 따른 실효 용량을 함께 확인한다.

## 4. 재검사 결과와 해석 범위

이번에 KiCad CLI **10.0.6**으로 두 원본 회로도의 ERC, PCB DRC와 회로도 일치 검사를 새로 실행하고 XML 넷리스트를 새로 출력했다. KiCad Python API로 현재 PCB와 새 넷리스트를 직접 비교했다.

| 확인 항목 | 6면 PCB | 8면 PCB |
|---|---:|---:|
| ERC 보고 위반 | 0 | 0 |
| DRC 보고 위반 | 0 | 0 |
| 미연결 / 회로도 불일치 | 0 / 0 | 0 / 0 |
| 비교한 연결 패드 | 234 | 234 |
| 패드 넷 차이 | 0 | 0 |
| 전기 부품 / SMT / THT | 74 / 55 / 19 | 74 / 55 / 19 |
| 트랙 선분 / 비아 | 698 / 63 | 704 / 57 |
| 최소 트랙 폭 | 0.1874 mm | 0.1874 mm |

과거 문서의 216패드 수와 달리 이번 검사는 현재 PCB의 넷 이름이 있는 모든 패드를 비교했다. 수량 차이를 설계 변경의 증거로 해석하지 않는다. 8면 PCB·기존 XML·견적 Gerber ZIP의 SHA-256은 조립 패키지의 `validation_and_sources.json` 기록과 모두 일치했다.

검사 규칙에 한계가 있다. DRC 보고서에는 missing_courtyard, track_not_centered_on_via, tuning_profile_track_geometries, footprint_filters_mismatch, footprint_type_mismatch의 **5개 ignore 항목**이 있다. 프로젝트의 개별 DRC 제외 목록은 비어 있지만 모든 검사 종류가 활성화된 상태는 아니다. 특히 custom 풋프린트의 조립 여유·부품 몸체 간섭과 제조사 DFM을 0건 결과로 보증할 수 없다. ERC에도 4개 ignored_checks가 있으며 세부 항목은 원본 보고서에 보존했다.

DRC의 일반 최소 간격은 0.20 mm, 드라이버 전원 넷 클래스는 0.25 mm, 최소 허용 트랙 폭은 0.15 mm다. 일부 신호 탈출부의 실제 폭 0.1874 mm는 설정된 규칙을 만족한다. 공급 전류에 적합한 동박 폭·두께·온도 상승을 따로 계산한 결과는 아니다.

## 5. 다음 제작 전에 해결할 사항

1. **업체 0.002 mm 간격 오류:** 기존 조립 안내에 미해결로 기록돼 있다. 이번 KiCad 재검사만으로 그 오류가 없어졌다고 판단할 수 없다. 업체가 지적한 층·좌표·객체 쌍과 실제 업로드 ZIP을 받아 동박, 같은 넷 경계, 마스크, 드릴 중 무엇인지 판별해야 한다. 현재는 발생 원인을 단정하지 않았다.
2. **U1/U2 품번 일관성:** 회로도·PCB 값은 `SN74HCT595D`, SMT BOM 구매 후보는 Nexperia `74HCT595D,118`이다. 실제 풋프린트는 SO16 3.9×9.9 mm, 피치 1.27 mm다. 검토한 TI SN74HCT595 데이터시트의 주문 정보는 TSSOP(PW)이며 이 SO16 풋프린트의 구매 근거로 사용할 수 없다. Nexperia 자료는 74HCT595D의 SO16을 명시한다. 새 설계에서는 제조사·MPN·패키지·회로도 값·BOM을 통일해야 한다. [Nexperia 데이터시트](https://assets.nexperia.com/documents/data-sheet/74HC_HCT595.pdf)
3. **송신기 확정:** 표시 V40AN16T의 실제 공급사·40 kHz 송신형·Ø16 mm·10 mm 핀 간격·리드 굵기·높이·연속 입력 정격을 확정한다. 음향 극성은 실물로 확인하고 채널별 보정한다.
4. **256채널 연결:** DATA 32개, 클록 두 그룹과 ARM의 배선·FPGA 헤더·GPIO를 결정한다. 긴 케이블과 다수 패널 부하는 클록 분배 버퍼·귀환 경로·파형으로 검증해야 한다. PCB 쪽 33 Ω만으로 전체 분배 품질은 확정되지 않는다.
5. **최신 좌표와 PC 통신:** 새 256좌표·법선·물리 채널 맵을 작성한다. `src/acousticstudio/hardware.py`는 256개 위상의 엄격한 프레임 길이 검사와 물리→소프트웨어 채널 맵 기능을 갖지만 새 패널 연결을 자동 추론하지 않는다. 기존 프로파일을 선택하는 것만으로 핀 순서가 맞아지는 것은 아니다.
6. **전원·조립·성능:** 전원/커넥터 전류 정격, 퓨즈·역극성 보호 필요성, 바닥면 전자부품과 리드/프레임 간섭, GND 직접 연결 패드의 납땜성을 검토한다. 한 패널에서 출력·위상·ARM·리플·온도를 확인한 뒤 전체 배열로 확장한다. 300 mm 터널의 음장·복원력·부양 성능은 새 좌표로 다시 계산하고 실험해야 한다.

## 6. 후속 변경 작업에 적용할 기준

사용자가 변경 요구를 주면 그 요구에 맞춰 면 수, 면당 PCB 수, 채널 수, 송신기 치수·배치, 터널 거리·촬영 틈, 구동 전압, 제어 보드, 조립 범위를 확정한다. 기존 설계는 보존하고 별도 리비전으로 회로도·PCB·필요한 라이브러리·제조 파일·BOM/PnP·핀/채널 맵·배열 좌표를 함께 갱신한다. 기구 치수가 바뀌면 Creo 참조 모델도 해당 범위에서 맞춘다.

검증은 회로도↔PCB 연결, ERC/DRC, 풋프린트/MPN, 조립 방향, Gerber 원점, 기구 간섭, 소프트웨어 좌표·채널 순서까지 구분해 기록한다. 실제 FPGA 컴파일·계측·부양 실험은 실행 여부와 결과를 별도로 적는다. 구체적인 변경 요구는 아직 받지 않았으므로 새 회로 제작이나 기존 오류 수정은 이번 분석 범위에 포함하지 않았다.

이 폴더의 증거 파일: `ERC_6f.json`, `DRC_6f.json`, `ERC_8f.json`, `DRC_8f.json`, `netlist_6f.xml`, `netlist_8f.xml`, `connectivity_review.json`. 비교 스크립트는 `../../scratch/review_pcb_20261006.py`이며 KiCad에 포함된 Python으로 실행한다.

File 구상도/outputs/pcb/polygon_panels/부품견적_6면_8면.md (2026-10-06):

# 6면·8면 패널 부품 예산 비교

작성일: 2026-10-04. 제조업체 확정 견적이 아니라 공개 판매 가격과 소량 구매 예산 단가를 이용한 추정이다. 두 후보를 각각 계산했으며 동시에 구매하는 것으로 합산하지 않았다.

## 제작업체 비용을 반영한 후속 견적

PCB 제작·실장 공임과 FPGA·전원·케이블·프레임까지 반영한 상세 계산은 [제작 및 추가부품 견적표](제작및추가부품견적_센서제외.md)에 추가했다. 아래 기존 부품별 표는 기판에 실장하는 부품값만 의미한다.

| 센서 제외 예산 | 6면 / 6장 | 8면 / 8장 |
|---|---:|---:|
| 해외 PCB 제작·실장·부품·배송·세금 예비액 | 약 21.5만~46.8만원 | 약 24.9만~51.7만원 |
| 국내 PCB 제작·실장·부품·배송·세금 예비액 | 약 92.5만~120.3만원 | 약 99.1만~128.0만원 |
| 별도 제어·전원·배선·프레임 구매 | 약 22.7만~41.0만원 | 약 24.7만~44.1만원 |
| **해외 제작 + 추가 구매 합계** | **약 44.2만~87.8만원** | **약 49.6만~95.8만원** |
| **국내 제작 + 추가 구매 합계** | **약 115.2만~161.2만원** | **약 123.8만~172.2만원** |

공개 업체 요금표와 명시한 가정을 적용한 시나리오다. 업체 전체의 통계적 평균이나 발주 확정 견적이 아니며, 특히 PCB 제작 패널 배치·해외 제작비·배송·조달 여유액은 미확정이다. 초음파 송신기 가격은 사용자 요청에 따라 이 파일과 후속 견적표에 반영하지 않았다. FPGA 펌웨어 및 어댑터 설계 외주비, 랑주뱅 하이브리드 추가 비용은 합계에서 제외했다.

## 계산 범위

- 6면: `panel_6faces_16ch`의 PCB 6장, 장당 60 × 180mm.
- 8면: `panel_8faces_16ch`의 PCB 8장, 장당 48 × 180mm.
- 두 회로도의 KiCad 분석 BOM은 값·풋프린트·수량이 동일하다. 회로도와 기존 XML 넷리스트의 전체 심벌 수는 각각 78개이며, 여기에는 송신기 16개와 기구용 홀 4개가 포함된다.
- 초음파 송신기 T1~T16, V40AN16T는 구매비와 업체 실장 범위에서 제외한다. 전체 제외 수량은 6면 96개, 8면 128개다.
- 계산 대상 전자부품은 장당 58개: SMD 55개, 삽입형 전해 커패시터 1개, 헤더 2개. 전체 348개 또는 464개.
- PCB 제작, SMT/THT 실장, 세팅·스텐실·부품 조달 수수료, 배송, 세금, FPGA·외부 전원·케이블·프레임 비용은 아래 부품 합계에 포함하지 않았다.
- USD 가격은 **예산 계산용 가정 환율 1달러 = 1,500원**을 적용했다. 실제 당일 환율이라는 뜻은 아니다.

## 부품별 계산

IC 단가는 공개 가격을 원화로 환산하고 반올림했다. 나머지 품목은 아래 공개 가격을 참고하되 판매처와 제조사 미확정에 따른 소량 구매 예산 범위를 적용했다. 표의 상한·하한은 모든 품목을 같은 판매처에서 담은 장바구니 확정 금액이 아니다. 최소 구매 수량과 여분은 별도다.

| 부품 / 규격 | 회로도 참조 | 장당 | 6장 | 8장 | 예산 단가(원/개) | 6장 부품값(원) | 8장 부품값(원) |
|---|---|---:|---:|---:|---:|---:|---:|
| TC4427A, SOIC-8 | U3~U10 | 8 | 48 | 64 | 1,250~1,700 | 60,000~81,600 | 80,000~108,800 |
| HCT595, SOIC-16; 아래 품번 확인 사항 참조 | U1,U2 | 2 | 12 | 16 | 350~650 | 4,200~7,800 | 5,600~10,400 |
| MMBT3904, SOT-23 | Q1 | 1 | 6 | 8 | 20~100 | 120~600 | 160~800 |
| 10kΩ, 0805 | R1~R17,R19 | 18 | 108 | 144 | 5~15 | 540~1,620 | 720~2,160 |
| 100kΩ, 0805 | R18,R22~R25 | 5 | 30 | 40 | 5~15 | 150~450 | 200~600 |
| 33Ω, 0805 | R20,R21 | 2 | 12 | 16 | 5~15 | 60~180 | 80~240 |
| 100nF, ≥50V, 0805 X7R | C1~C8 | 8 | 48 | 64 | 30~50 | 1,440~2,400 | 1,920~3,200 |
| 100nF, ≥16V, 0805; 50V 제품 사용 가능 | C9,C10 | 2 | 12 | 16 | 30~50 | 360~600 | 480~800 |
| 1µF, ≥50V, 0805 X7R | C11~C18 | 8 | 48 | 64 | 70~150 | 3,360~7,200 | 4,480~9,600 |
| 10µF, ≥16V, 0805 | C20 | 1 | 6 | 8 | 150~250 | 900~1,500 | 1,200~2,000 |
| 220µF, ≥25V, 지름6.3mm / 피치2.5mm | C19 | 1 | 6 | 8 | 150~400 | 900~2,400 | 1,200~3,200 |
| 2×5 핀 헤더, 피치2.54mm | J1 | 1 | 6 | 8 | 100~300 | 600~1,800 | 800~2,400 |
| 1×3 핀 헤더, 피치2.54mm | J2 | 1 | 6 | 8 | 50~125 | 300~750 | 400~1,000 |
| **합계** | | **58** | **348** | **464** | | **72,930~108,900** | **97,240~145,200** |

기판 한 장의 실장 부품값은 약 **12,155~18,150원**이다. 같은 단가 조건에서 8면은 6면보다 약 **24,310~36,300원** 더 든다. PCB 폭 차이에 따른 제작비 차이는 이 계산에 들어 있지 않다.

실제 구매에서는 최소 수량, 포장 단위, 실장 손실·수리 여분을 고려해야 한다. 부품 구매 예산으로 **6면 8만~13만원, 8면 11만~17만원** 정도를 잡을 수 있다. 이 금액에도 제작·실장·배송·세금은 포함하지 않았다. 제조업체의 부품 재고와 조달 방식에 따라 달라질 수 있으며 확정 상한은 아니다.

## 공개 가격 근거

검색 요약과 상품 페이지에 가격 차이가 있어 직접 연 상품 페이지에 표시된 구간 가격을 우선했다. 아래 숫자는 조회 당시의 표시 가격이며 이후 변경될 수 있다.

1. [LCSC TC4427ACOA713, C144234](https://www.lcsc.com/product-detail/C144234.html): 30개 이상 **$0.8269/개**. 48개 약 59,537원, 64개 약 79,382원. 견적 단가는 1,250원으로 반올림했다. `713`은 테이프·릴 포장 후보이며, 업체 구매 시 정확한 주문 품번을 명시한다.
2. [DigiKey TC4427ACOA](https://www.digikey.kr/ko/products/detail/microchip-technology/TC4427ACOA/418664): 25개 이상 **1,656.48원/개**. 48개 약 79,511원, 64개 약 106,015원. 예산 상한 단가는 1,700원으로 반올림했다. 48/64개에는 100개 이상 할인 단가를 적용하지 않았다.
3. [LCSC Nexperia 74HCT595D,118, C282339](https://www.lcsc.com/product-detail/C282339.html): 5개 이상 **$0.2313/개**, 구매 단위 5개. 예산 환율로 약 347원/개이며, 실장 12개에는 최소 15개, 16개에는 최소 20개 구매가 필요하다.
4. [DigiKey Nexperia 74HCT595D,118](https://www.digikey.kr/ko/products/detail/nexperia-usa-inc/74HCT595D-118/763413): 검색으로 확인한 10개 구간 **602.10원/개**를 상한 예산의 참고로 사용했다. 업체 조달 확정 가격은 아니다.
5. [LCSC Yageo CC0805KRX7R9BB104, C49678](https://www.lcsc.com/product-detail/C49678.html): 100nF/50V/X7R/0805, 20개 이상 **$0.0191/개**, 20개 단위. C1~C10을 같은 정격의 부품으로 구매하면 6면 총 60개, 8면 총 80개다.
6. [LCSC CCTC TCC0805X7R105K500DT, C376926](https://www.lcsc.com/product-detail/C376926.html): 1µF/50V/X7R/0805, 20개 이상 **$0.0349/개**, 20개 단위. 조회 시 재고가 있었으며 예산 단가는 판매처 차이를 고려해 70~150원으로 설정했다. 최종 품번과 재고는 업체에 확인한다.
7. [LCSC Samsung CL21A106KAYNNNE, C15850](https://www.lcsc.com/product-detail/C15850.html): 10µF/25V/0805, 재고 없음, 표시 가격은 참고용. 해당 품목의 저가 표시를 즉시 구매 가능한 가격으로 계산하지 않았으며 150~250원의 예산 단가를 사용했다.
8. [LCSC Rubycon 25YXJ220M6.3X11, C88729](https://www.lcsc.com/product-detail/C88729.html): 220µF/25V/지름6.3mm/피치2.5mm, 5개 이상 **$0.0826/개**, 5개 단위. 두 후보 모두 최소 10개 구매가 필요하다. 예산 단가는 판매처 차이를 반영해 150~400원으로 설정했다.
9. [LCSC MMBT3904, C20526](https://www.lcsc.com/product-image/C20526.html): 표시 가격 **$0.0117/개**, 최소 50개. 따라서 실장 수량 6개/8개만 곱한 값보다 실제 결제액이 크다. 저항·헤더의 제조사 품번과 단가는 미확정 예산 항목이다.

## 제작 전에 구매 품번을 확정할 항목

**U1/U2의 설계 표기 `SN74HCT595D`를 그대로 발주 품번으로 쓰지 않는다.** [TI의 현재 SN74HCT595 제품 페이지](https://www.ti.com/product/SN74HCT595)는 TSSOP(PW)를 표시한다. 현재 PCB의 `Levitation:SOIC16`과 패키지가 다르다. 이번 가격 계산은 [Nexperia 74HCT595D](https://www.nexperia.com/product/74HCT595D)의 SO16 제품 `74HCT595D,118`을 대체 후보로 가정했다. 제조업체에 회로도 핀 기능과 실제 풋프린트 치수 대조 후 대체 승인을 요청한다. 이 문서는 전기적 대체 검증 보고서가 아니며 설계 원본도 수정하지 않았다.

C19는 용량·전압뿐 아니라 지름6.3mm와 핀 간격2.5mm가 맞아야 한다. J1/J2는 현재 일반 핀 헤더 풋프린트 기준이며, 산업용 전원 커넥터로 변경하는 비용은 포함하지 않았다. 저항·대부분 커패시터·헤더는 회로도에 제조사 품번이 없으므로 업체 BOM에서 구체적인 품번을 정해야 한다.

## 업체 견적 요청에 넣을 조건

아래 두 안 중 선택한 한 안만 주문한다.

> A안: 60×180mm, 2층 FR-4, 1.6mm, 완성 패널 6장. 또는 B안: 48×180mm, 2층 FR-4, 1.6mm, 완성 패널 8장. 초음파 송신기 T1~T16은 고객이 직접 실장하므로 부품 구매 및 실장에서 제외. 나머지 58개/장 부품의 구매 및 실장을 요청. U1/U2는 SOIC-16 HCT595 구매 품번을 먼저 확정. PCB 제작비, 부품비, SMD 실장비, 전해 커패시터·헤더 삽입 실장비, 세팅/스텐실/조달비, 배송·세금을 분리해서 견적 요청. 최소 주문 수량 때문에 여분의 빈 기판이 생기는 경우 완성품 수량과 별도 표시.

[JLCPCB 공식 실장비 안내](https://jlcpcb.com/help/article/pcb-assembly-price)는 부품값 외에 세팅, 스텐실, 납땜, 피더 로딩 등의 항목을 따로 계산한다. LCSC 소매 부품가격을 JLCPCB나 국내 업체의 PCBA 부품가격과 동일하다고 가정하지 않는다. 실제 PCB 제작·실장 비용은 파일·부품·주문 조건을 넣은 업체 견적으로 확정해야 한다.

## 검증 범위와 신뢰도

- **높음:** 두 회로도 BOM의 수량 동일 여부 및 XML 넷리스트의 전체 개수 교차 확인. 초음파 송신기 제외 수량과 곱셈 검산.
- **중간:** 조회 시점의 공개 가격을 이용한 부품 예산. 미지정 제조사 품번, 구매 단위, 공급처·환율에 따라 변동.
- **미확정:** 제조업체의 실제 부품 조달·PCB 제작·실장 최종 견적 및 대체품 승인.
- 수행한 작업: 두 회로도의 BOM 분석, 기존 XML/부품 구성 문서 대조, 온라인 가격 조사. 새 DRC/ERC·열·SPICE·음향 검증은 이 부품 견적 범위에 포함하지 않았다.

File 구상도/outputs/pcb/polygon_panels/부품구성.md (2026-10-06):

# 시제품 부품 구성

아래 수량은 실장 수량이며 여분은 제외했다. 가격표가 아니다. 부품의 정확한 제조사 품번과 치수는 구매 전에 확정해야 한다.

| 부품 | 값 / 패키지 | 패널당 | 6면 전체 | 8면 전체 |
|---|---|---:|---:|---:|
| 송신기 | V40AN16T, 외경16mm, 핀 간격10mm | 16 | 96 | 128 |
| 시프트 레지스터 | SN74HCT595D, SOIC-16 3.9×9.9mm, 1.27mm 피치 | 2 | 12 | 16 |
| 듀얼 드라이버 | TC4427ACOA, 비반전, SOIC-8 3.9×4.9mm | 8 | 48 | 64 |
| 출력 활성화 NPN | MMBT3904, SOT-23, 핀1 B/2 E/3 C | 1 | 6 | 8 |
| 저항 | 10kΩ, 0805 | 18 | 108 | 144 |
| 저항 | 100kΩ, 0805 | 5 | 30 | 40 |
| 저항 | 33Ω, 0805 | 2 | 12 | 16 |
| 드라이버 바이패스 | 100nF, ≥50V, 0805 | 8 | 48 | 64 |
| 논리 바이패스 | 100nF, ≥16V, 0805 | 2 | 12 | 16 |
| 드라이버 로컬 용량 | 1µF, ≥50V, 0805 | 8 | 48 | 64 |
| 논리 전원 용량 | 10µF, ≥16V, 0805 | 1 | 6 | 8 |
| 드라이버 벌크 용량 | 220µF, ≥25V, 지름6.3mm·핀 간격2.5mm | 1 | 6 | 8 |
| J1 신호 헤더 | 2×5, 2.54mm 피치 | 1 | 6 | 8 |
| J2 전원 헤더 | 1×3, 2.54mm 피치 | 1 | 6 | 8 |
| PCB | 2층 FR-4, 1.6mm | 1 | 6 | 8 |

J1/J2는 시제품용 일반 헤더 풋프린트다. 실제 구매품의 전류 정격과 케이블, 역삽입 방지 및 키 방향을 확정한 산업용 커넥터 설계는 아니다. 전해 커패시터의 지름과 핀 간격은 기판 풋프린트에 맞춰야 하며, 전압·용량만 맞는 제품을 임의로 대체하지 않는다.

별도 필요품: FPGA 코어 보드, PC 연결 수단, 논리/드라이버 전원과 변환기·분배부, 필요 시 클록 버퍼, 신호 케이블, 프레임과 브래킷, 나사·스페이서. 이 패키지에는 해당 보드들의 회로·제조 파일이 포함되지 않는다.

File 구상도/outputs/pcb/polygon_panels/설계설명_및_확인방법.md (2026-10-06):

# 6면·8면 초음파 부양 패널 PCB P0

작성일: 2026-10-04. 16mm 송신기, 기존 128채널 이내 조건, 8채널 회로 반복 구조를 기준으로 만든 **시제품 설계**다. 각 폴더에는 수정 가능한 KiCad 회로도·배선 완료 PCB·프로젝트·로컬 부품 라이브러리가 있다. KiCad 10.0.6으로 불러오고 검사했다.

## 1. 개수 선정의 의미

**음향적으로 최적인 개수는 아직 확정할 수 없다.** 부양할 물체의 크기·밀도, 실제 구동 전압, 목표 이동 범위, 터널 치수가 확정되지 않았다. 이번에는 제작과 제어의 표준화를 우선한 추천 후보를 선정했다. 사용자 응답 전까지 기존 128채널 이내 조건과 예시 치수를 유지했다.

| 항목 | 6면 후보 | 8면 후보 |
|---|---:|---:|
| 패널 수 | 6 | 8 |
| 패널당 송신기 | 16 = 2열 × 8행 | 16 = 2열 × 8행 |
| 전체 송신기 / 독립 출력 | **96** | **128** |
| 마주 보는 방사면의 평면 간 거리 | 150mm 가정 | 150mm 가정 |
| 길이 방향 중심 간격 | 20mm | 20mm |
| 폭 방향 중심 간격 | 18mm | 18mm |
| 송신기 부분 길이 / 폭 | 156mm / 34mm | 156mm / 34mm |
| PCB 한 장 크기 | **60 × 180mm** | **48 × 180mm** |
| PCB 동박 층수 / 두께 | 2층 / 1.6mm | 2층 / 1.6mm |
| 레지스터 / 듀얼 드라이버, 패널당 | 2 / 8 | 2 / 8 |
| 레지스터 / 듀얼 드라이버, 전체 | 12 / 48 | 16 / 64 |

선정 이유는 같은 16채널 회로를 반복하면서, 행 수·송신기 간격·예시 터널 크기를 동일하게 두어 6면과 8면의 차이를 비교할 수 있기 때문이다. 6면 기판은 넓은 고정 여유를 두었고, 8면 기판은 패널 폭을 줄였다. 고정 구조를 바꾸면 공통 크기의 기판으로 통일할 수도 있다. 서로 다른 기판 폭이 음향 성능을 개선한다고 주장하지 않는다.

대안으로 6면 120개(패널당 2×10), 6면 126개(3×7), 6면 144개(3×8), 8면 192개(3×8)도 가능하다. 120개는 배열 길이가 증가하고, 126개는 패널당 24출력 회로 중 21개만 쓰는 등의 구성이 필요하다. 144개와 192개는 기존 128채널 조건을 넘는다. 이 대안들을 음향적으로 열등하다고 판정한 것이 아니다. **최대 부양력만을 목표로 하면 추천 개수와 형상이 달라질 수 있다.**

16mm 후보 송신기의 지향각은 약 60°(전각, -6dB 기준)다. 이번 평면 배열에서 중앙 높이 90mm로 향하는 끝 행의 방향 차이는 약 43°다. 끝 행의 소리가 중앙에 도달하지 않는다는 뜻은 아니지만, 중앙을 향해 개별적으로 기울인 배열보다 감쇠가 클 수 있다. 긴 배열은 길이 방향 이동을 검토하기 위한 형상이다. 중앙 한 점의 힘을 최대화하는 배열과 동일하지 않다.

## 2. 기존 SonicSurface에서 참고한 것

원본 위치:

`simulations/SonicSurface/Electronics/16x16 10mm transducers SMD PCB Gerbers/SonicSurface1.2_2Layers_183x169/Project Outputs for SonicSurface/`

원본에는 Gerber·드릴·부품 좌표가 있으며, 수정 가능한 KiCad/Altium 회로도 원본은 발견되지 않았다. 이번 회로도는 기존 제조 파일의 연결 추적, 논문의 Figure 2, 부품 데이터시트를 대조해 **새로 작성한 회로도**다. 원본 기판을 단순히 확대하거나 축소한 파일이 아니다.

원본에서 유지한 구조:

- 시프트 레지스터 출력 8개 → 듀얼 드라이버 4개 → 송신기 8개.
- 송신기 한 핀은 독립 드라이버 OUT, 다른 핀은 GND. 브리지 구동이 아니다.
- 논리 전원과 드라이버 전원을 구분하고 GND는 공통으로 연결.
- 레지스터마다 독립 직렬 DATA를 공급하고 SHIFT/LATCH 타이밍은 공유.

새 설계에서 바꾼 것:

- 10mm 송신기용 약 5mm 핀 간격을 16mm V40AN16T용 **10mm 핀 간격**으로 변경.
- 5V에서 사용하는 레지스터를 **SN74HCT595D**로 지정. 3.3V FPGA 입력을 받는 조건에서 74HC595의 입력 임계값을 무조건 만족한다고 가정하지 않음.
- 드라이버를 비반전 **TC4427ACOA, SOIC-8**로 지정. 핀 번호를 제조사 자료와 대조.
- 원본의 /OE GND 고정 대신 출력 활성화 제어 **ARM** 추가. Q1 MMBT3904가 3.3V ARM으로 /OE를 낮추며, 기본 상태는 비활성으로 설계.
- 레지스터가 비활성일 때 드라이버 입력이 뜨지 않도록 채널마다 10kΩ 풀다운 추가.
- 각 드라이버 가까이 100nF 및 1µF, 패널 전원에 벌크 커패시터 추가.
- 송신기 번호와 IC 번호를 기판에 표시. 전체 부품 번호와 외형은 F.Fab/B.Fab에 포함.

근거: [논문](https://doi.org/10.3390/app11072981), [원본 공개 저장소](https://github.com/upnalab/SonicSurface), [TI SN74HCT595](https://www.ti.com/lit/ds/symlink/sn74hct595.pdf), [Microchip TC4427A](https://ww1.microchip.com/downloads/aemDocuments/documents/APID/ProductDocuments/DataSheets/TC4426A-TC4427A-TC4428A-1.5A-Dual-High-Speed-Power-MOSFET-Drivers-2000142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).

기존 분석 근거는 `outputs/reference_analysis/sonicsurface_analysis/SonicSurface_동박연결_검증.md`와 `SonicSurface_원문근거_대조.md`에 보관되어 있다.

## 3. 패널 연결

**아래 핀 번호는 새 패널 PCB의 커넥터 번호다. Waveshare FPGA 보드의 헤더 번호와 동일하지 않다.**

| J1 핀 | 기능 | 연결 방향 |
|---:|---|---|
| 1 | GND | FPGA와 공통 접지 |
| 2 | +5V | 패널 논리 전원 |
| 3 | DATA_A | FPGA → U1, 로컬 채널 0~7 |
| 4 | GND | 신호 귀환 |
| 5 | DATA_B | FPGA → U2, 로컬 채널 8~15 |
| 6 | GND | 신호 귀환 |
| 7 | SHIFT_PIN | FPGA 시프트 클록 → 33Ω → SHIFT |
| 8 | LATCH_PIN | FPGA 래치 클록 → 33Ω → LATCH |
| 9 | ARM | FPGA 3.3V HIGH로 출력 활성화, LOW로 비활성화 |
| 10 | GND | 신호 귀환 |

| J2 핀 | 기능 |
|---:|---|
| 1 | DRV_VDD, 드라이버 전원 |
| 2 | GND |
| 3 | +5V, 논리 전원 |

J1의 +5V와 J2의 +5V는 같은 망이다. 같은 5V 전원을 분배하며, 서로 독립된 전원을 임의로 병렬 연결하지 않는다. +5V를 FPGA의 3.3V GPIO에 연결하는 방식이 아니다. 각 패널의 전원은 외부 분배부에서 공급한다. 패널 자체에는 12→5V 변환기나 FPGA 전원 회로가 없다.

DRV_VDD의 실제 운전값은 송신기의 연속 구동 허용치와 시제품 계측으로 정해야 한다. TC4427A의 동작 전압 범위는 4.5~18V다. V40AN16T의 80Vpp impulse 수치를 연속 운전 전압으로 사용하지 않는다. 두 부품의 정격을 함께 만족해야 한다.

각 송신기의 상대 음향 극성을 측정하고 보정해야 한다. PCB의 T 핀 1은 해당 OUT, 핀 2는 GND라는 배선 정의이며 제조사 표기가 실제 음향 위상을 보장한다는 뜻이 아니다.

## 4. 채널과 FPGA 통합

패널은 P0부터 번호를 매긴다. 로컬 송신기는 T1~T16이고, 로컬 채널은 0~15다. 배열 JSON의 전역 채널은 `패널번호*16 + 로컬채널`이다. 첫 4행은 U1, 뒤 4행은 U2가 담당한다.

각 레지스터의 로컬 출력 0~7은 실제 핀 15, 1, 2, 3, 4, 5, 6, 7에 대응한다. 전송 비트 순서는 FPGA 소스와 실제 파형을 함께 확인해야 하며, JSON의 순서만으로 기존 펌웨어와 호환됨을 판정하지 않는다.

기존 `Firmware/FPGA primary/QuadrupleBuffer.qsf`에는 DATA[0..31]과 SHIFT_CLOCK_1/2, LATCH_CLOCK_1/2의 칩 핀 할당이 있다. 새 96채널에는 DATA 12줄, 128채널에는 16줄이 필요하다. 실제 코어 보드 헤더 위치와 ARM GPIO 할당은 아직 확정하지 않았다. **이 패키지는 FPGA 어댑터 보드나 수정·컴파일한 FPGA 펌웨어를 포함하지 않는다.**

패널마다 짧은 신호 케이블을 사용하고, 클록 분배는 6면 3+3 또는 8면 4+4처럼 나누는 안을 검토할 수 있다. 버퍼, 직렬 저항, 케이블 길이와 분기 방식은 파형 측정으로 확정한다. PCB의 33Ω만으로 긴 케이블의 신호 품질을 보장하지 않는다.

시제품에서는 ARM을 LOW로 유지한 상태에서 공급 전압과 레지스터 데이터를 안정화한 뒤 활성화한다. 전원 순서 전체와 비정상 상태에서의 출력 차단은 실제 계측이 필요하다.

## 5. KiCad에서 확인하는 방법

1. KiCad를 실행하고 해당 폴더의 `panel_6faces_16ch.kicad_pro` 또는 `panel_8faces_16ch.kicad_pro`를 연다. 이 PC에는 KiCad 10.0.6을 설치했다.
2. **회로도 편집기**에서 `.kicad_sch`를 연다. 같은 이름의 넷 라벨은 선을 길게 그리지 않아도 전기적으로 연결되어 있다. 예를 들어 U1의 IN00과 U3의 IN00은 같은 망이며 U3의 OUT00은 T1로 간다.
3. **PCB 편집기**에서 `.kicad_pcb`를 연다. F.Cu/B.Cu는 배선, F.Silkscreen/B.Silkscreen은 인쇄, F.Fab/B.Fab은 전체 부품 번호와 조립 외형이다. T는 안쪽 면, U·R·C·Q·커넥터는 바깥쪽 면이다.
4. 부품 위에서 `E`를 눌러 값, 풋프린트와 패드 넷을 확인한다. 넷 강조 기능으로 `OUT00`을 선택하면 드라이버와 송신기 사이 연결을 추적할 수 있다. `/`는 회로도 로컬 넷 이름에 붙는 경로 표기다.
5. PCB 편집기에서 **보기 → 3D 뷰어**, 또는 `Alt+3`을 누른다. 송신기는 외경 16mm·높이 12.5mm의 단순 외형 모델이다. 메시·전극·실제 내부 형상을 재현한 정밀 모델은 아니다.
6. **검사 → 디자인 규칙 검사(DRC)**를 실행하고, 가능하면 회로도와 일치 여부도 검사한다. 회로도 편집기에서도 **검사 → 전기 규칙 검사(ERC)**를 실행한다. 수정 후에는 접지 영역을 다시 채우고 검사한다.
7. Gerber 뷰어에서 `gerbers_P0`의 동박·마스크·외곽과 `.drl`을 함께 연다. 기판 외곽, 송신기 10mm 핀 간격, 고정홀, 부품 패드를 확인한다.

프로그램 없이 먼저 보려면 `PCB_6_8_comparison.png`, 각 폴더의 `pcb_top.png`, `pcb_bottom.png`, `schematic_preview.png`를 연다. 회로도 SVG와 동박/조립 SVG는 브라우저에서 확대해서 볼 수 있다.

`assembly_6faces_CONCEPT.scad`와 `assembly_8faces_CONCEPT.scad`는 OpenSCAD용 조립 개념 모델이다. 프레임에는 최종 고정 탭, 전자부품·케이블 회피 형상과 나사 체결 상세가 들어 있지 않다. OpenSCAD 자체를 설치하거나 이 모델을 렌더링한 상태는 아니다. 조립 PNG는 동일한 배열 좌표로 생성했다.

## 6. 완료한 검사

| 검사 | 6면 패널 | 8면 패널 |
|---|---:|---:|
| KiCad ERC 위반 | 0 | 0 |
| KiCad DRC 위반 | 0 | 0 |
| 미연결 항목 | 0 | 0 |
| 회로도와 PCB 불일치 | 0 | 0 |
| 설계 명세·회로도 넷리스트·PCB가 일치하는 연결 패드 | 216 | 216 |
| 접지 동박 | 앞·뒤 채움 | 앞·뒤 채움 |
| 최소 실제 배선 폭 | 0.1874mm | 0.1874mm |

일반 신호의 목표 폭은 0.25mm, 드라이버 전원은 0.8mm, 논리 전원/접지 배선은 0.4mm다. 일부 패드 주변의 짧은 신호 탈출 구간은 약 0.1874mm로 줄어든다. 최소 제조 규칙은 0.15mm, 일반 간격 0.20mm, 드라이버 전원 간격 0.25mm로 설정했다. 위반을 제외 처리해 0으로 만든 것이 아니다. 기존 회로 구조를 그대로 확대/축소하지 않고 새로 배선했으며 실제 배선과 회로도 일치 검사를 수행했다.

GND 동박은 패드에 직접 연결한다. 접지 납땜 패드는 가열이 더 필요할 수 있으므로 적절한 납땜 공정과 지그를 검토한다. 송신기 핀의 뒤쪽 돌출 길이도 전자부품과 간섭하지 않도록 실물에서 확인하고 정리해야 한다.

재검사는 폴더에서 다음 명령으로 할 수 있다:

```powershell
powershell -NoProfile -ExecutionPolicy Bypass -File .\verify_designs.ps1
```

스크립트는 KiCad CLI로 두 설계의 ERC·DRC·회로도 일치를 검사하고 `recheck` 폴더에 보고서를 저장한다. 전역 실행 정책을 바꾸는 명령이 아니다.

## 7. 제작 전에 남은 확인

Gerber/드릴 파일은 **P0 시제품 후보 출력물**이며, 실물 동작 검증을 마친 제작 승인본은 아니다. 구매할 송신기의 핀 굵기·간격·음향 극성, 정확한 부품 패키지, 커넥터 정격과 방향, 프레임 고정 간섭을 확인해야 한다.

한 패널 시제품에서 출력 파형, 위상, 전원 리플, 온도 상승과 ARM 동작을 확인한 뒤 전체 패널로 확장한다. 부양력은 물체의 중량을 버틸 수 있는 수직 힘과 3축 복원력을 함께 검증해야 한다. 터널을 세우거나 눕힌 경우의 중력 방향도 모델에 반영한다. 배열 좌표 JSON은 이를 위한 입력 자료이며, 음장 계산 결과가 아니다.

PCB ERC/DRC 통과는 부양 성공, 연속 구동 안전 전압, FPGA 통합 완료 또는 제조사의 DFM 승인을 의미하지 않는다.

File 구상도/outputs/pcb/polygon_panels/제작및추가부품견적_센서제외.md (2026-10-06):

# 제작업체 공임 및 추가 구매품 견적 — 초음파 송신기 비용 제외

작성일: 2026-10-04. 6면형은 패널 6장, 8면형은 패널 8장으로 각각 계산했다. 둘 중 하나만 만든다. 초음파 송신기의 구매비·실장비는 사용자 요청에 따라 모든 파일 합계에서 제외했다.

## 견적의 의미

공개 단가표로 확인한 **대표 업체의 요금에 설계 수량을 적용한 예산**이다. 업체 전체의 평균 거래가격을 통계적으로 조사한 자료는 아니다. 설계 파일을 업체에 보내거나 실제 견적 요청·주문을 하지 않았다.

- **공개 요금:** 국내 SMT 세팅·장당 공임·DIP 납땜·마스크 시작 가격, 국내 Working Sheet 제조 단가, JLCPCB 실장 항목별 단가, 일부 추가 구매품 가격.
- **계산 가정:** 국내 제작용 Working Sheet 2~3장, 해외 베어 PCB 3만~6만원, 배송·조달 여유액, 프레임 및 어댑터 자재 예비액. 실제 품목/설계 확정 시 바뀐다.
- **세금 예비액:** 업체 제작 항목에는 보수적으로 소계의 10%를 일괄 추가했다. 실제 세금·통관 수수료 정산표가 아니다. 이미 부가세를 포함한 추가 구매품에는 다시 10%를 더하지 않는다.
- **환율:** 1달러 = 1,500원은 예산 가정이다.

## 설계에서 확인한 공임 산정 수량

| 항목 | 한 장 | 6면 전체 | 8면 전체 |
|---|---:|---:|---:|
| PCB 크기 | 6면 60×180mm / 8면 48×180mm | 6장 | 8장 |
| SMD 부품 | 55개 | 330개 | 440개 |
| SMD 납땜 패드 | 187점 | 1,122점 | 1,496점 |
| 업체 실장할 THT 부품 | 3개: C19,J1,J2 | 18개 | 24개 |
| 업체 실장할 THT 납땜 핀 | 15점 | 90점 | 120점 |

PCB 원본의 풋프린트와 패드를 파싱해 수량을 확인했다. 송신기와 기구 홀은 제외했다. SMD는 B면에 있고, 사용자 송신기는 F면에 달린다. 센서를 뺀 업체 SMD 공정은 한쪽 면이므로 국내 표의 단면 구간을 적용한다. SMD 부품 종류는 20종 미만, 장당 55개이므로 100점 미만 구간이다. 납땜 패드 수와 부품 실장 개수를 혼동하지 않았다.

## 1. 국내 제조 및 국내 실장 시나리오

[샘플피씨비 공개 SMT 가격표](https://www.samplepcb.co.kr/shop/estimate_intro.php?category=assembly)의 20종 미만·100점 미만·단면 작업 구간은 세팅 250,000원, 장당 생산 13,000원이다. DIP는 150원/POINT, 메탈마스크는 110,000원부터 별도다. 릴 부품 기준이며 컷테이프 피더 작업 등은 추가 견적 대상이다.

[도일랩스 공개 제조 가격표](https://doillabs.com/pricing)의 2층 FR-4 단가는 Working Sheet 2장 주문 시 장당 147,000원, 3장 시 장당 144,000원이다. **Working Sheet는 250×330mm 이내 생산판을 뜻하며 완성 패널 PCB 한 장이 아니다.** 완성 패널 6/8장에 15만원을 각각 곱하지 않았다. 두 기판 모두 폭·길이와 제작 여백을 고려한 실제 배열 확정 전이므로 생산판 2~3장을 가정해 294,000~432,000원을 반영했다. 가능한 배치에 대한 업체 승인을 받은 값은 아니다.

두 업체의 공개 요금을 결합한 비교 모델이며, 한 업체가 이 가격에 일괄 제작하겠다는 견적이 아니다.

| 항목 | 계산 기준 | 6면(원) | 8면(원) | 근거 |
|---|---|---:|---:|---|
| 실장 부품 구매 | 기존 BOM, 최소수량·여분 반영 | 80,000~130,000 | 110,000~170,000 | 기존 부품 견적 |
| 베어 PCB 제조 | Working Sheet 2~3장 | 294,000~432,000 | 294,000~432,000 | 공개 단가 × 가정 장수 |
| SMT 세팅 | 동일 디자인 1회 | 250,000 | 250,000 | 공개 요금 |
| SMD 생산 공임 | 13,000원 × 완성 장수 | 78,000 | 104,000 | 공개 요금 |
| 메탈마스크 | 110,000원부터, 상한은 여유액 | 110,000~150,000 | 110,000~150,000 | 공개 시작가 + 가정 |
| C19,J1,J2 수삽 납땜 | 15점 × 장수 × 150원 | 13,500 | 18,000 | 공개 요금 |
| 부품 조달·컷테이프 등 여유액 | 확정 수수료가 아님 | 10,000~30,000 | 10,000~30,000 | 예산 가정 |
| 패널 배송 | 업체 확정 전 | 5,000~10,000 | 5,000~10,000 | 예산 가정 |
| 세전 모델 소계 | 위 항목 합계 | 840,500~1,093,500 | 901,000~1,164,000 | 계산 |
| 세금 예비액 | 소계 × 10% | 84,050~109,350 | 90,100~116,400 | 계산 가정 |
| **업체 제작 예산 합계** | | **924,550~1,202,850** | **991,100~1,280,400** | 송신기 제외 |

장당 배분 비용은 약 15.4만~20.0만원 또는 12.4만~16.0만원이다. 고정 세팅 비용을 나눠 부담하므로 8장 주문이 장당으로는 낮아도 총액은 더 크다. 세팅·마스크 포함 범위를 확인해 중복 청구가 없는지 업체 견적에서 대조해야 한다. 별도 기능시험 지그·시험 프로그램·엔지니어링 비용이 요구되면 추가된다.

국내 제조비 절감을 원하면 저렴한 공동생산 업체 또는 해외에서 만든 빈 PCB를 국내에 사급하는 별도 조합도 가능하다. 이 조합은 위 국내 전량제작 모델과 다르다.

## 2. 해외 제조·실장 시나리오

[JLCPCB 공식 공임표](https://jlcpcb.com/help/article/pcb-assembly-price)에 표시된 Economic 세팅 $8.18, 스텐실 $1.53, SMT $0.0016/점, 확장 부품 피더 $3.07/종, 수동 실장 $0.0164/점, 수땜 작업 $3.58/주문을 참고했다. 실제 Basic/Extended 분류와 실장용 재고는 확정하지 않았다.

Economic에서 확장 부품 3종을 가정하면 다음 계산으로 실장 기본 공임은 약 39,332원/6장, 40,967원/8장이다.

`(8.18 + 1.53 + 3.07×3 + 0.0016×187×장수 + 0.0164×15×장수 + 3.58 + 0.45) × 1,500`

Standard 전환·피더·지그 등 항목이 붙는 경우를 대비해 실장 예산 상한을 약 15만원대로 설정했다. **이 값은 현재 주문 시스템에서 해당 Gerber/BOM으로 생성한 가격이 아니다.**

[공식 실장 규격](https://jlcpcb.com/capabilities/pcb-assembly-capabilities)상 Economic은 단면 SMT/THT를 지원한다. Standard의 단일 기판 최소 크기는 70×70mm여서 현재 폭 60/48mm 기판이 Standard로 전환되면 제조용 테두리나 묶음 배치가 필요할 수 있다. 송신기 홀이 막히지 않도록 실장 제외 항목도 정확히 지정해야 한다.

| 항목 | 6면(원) | 8면(원) | 근거 |
|---|---:|---:|---|
| 실장 부품 구매 | 80,000~130,000 | 110,000~170,000 | 기존 BOM 예산; PCBA 공급 가격은 별도 |
| 베어 PCB 제조 | 30,000~60,000 | 30,000~60,000 | 크기·일반 사양·빈 PCB 여분을 고려한 예비액; 실시간 견적 미확인 |
| 세팅·스텐실·SMD·THT 실장 | 40,000~150,000 | 41,000~155,000 | 공식 공임 계산 + 서비스 변경 여유액 |
| 조달·기타 공정 여유액 | 10,000~25,000 | 10,000~25,000 | 예산 가정 |
| 국제 배송 | 35,000~60,000 | 35,000~60,000 | 무게·배송지 미입력 예비액 |
| 소계 | 195,000~425,000 | 226,000~470,000 | 계산 |
| 세금 예비액 10% | 19,500~42,500 | 22,600~47,000 | 실제 통관 정산과 다를 수 있음 |
| **업체 제작 예산 합계** | **214,500~467,500** | **248,600~517,000** | 송신기 제외 |

길이 180mm이므로 100×100mm 이하의 $2/5장 광고가격을 그대로 적용하지 않았다. 실제 6/8장 실장 가능 수량 및 빈 PCB 최소수량은 주문 시 확인해야 한다. 재고 부품으로 주문 가능한 경우의 시나리오이며 부품 사급/외부조달 변경은 금액과 납기를 바꿀 수 있다.

## 3. 기판 외에 필요한 구매품

모두 새로 구매하고 PC·납땜 도구·계측기는 이미 사용 가능한 것으로 가정한다. 완제품·모듈을 이용하고 FPGA 어댑터 및 배선 조립은 직접 수행하는 예산이다. 프레임은 소형 PoC의 프로파일/인쇄 브래킷/나사 수준이며 정밀 가공 프레임이 아니다. 아래 범위는 부가세 포함 또는 이에 상당하는 구매 예산이다.

| 항목 | 수량 / 용도 | 6면(원) | 8면(원) | 가격 상태 |
|---|---|---:|---:|---|
| Waveshare CoreEP4CE6 FPGA | 1개, 전체 96/128채널 제어 후보 | 65,000~95,000 | 65,000~95,000 | 공식 $38.99 참고 + 세금·판매처 차이 |
| USB Blaster 호환 프로그래머 | 1개, FPGA 다운로드 | 3,960~11,000 | 3,960~11,000 | 국내 공개가 3,960원부터 |
| CP2102 USB-UART | 1개, PC 통신; 3.3V 신호 조건 확인 | 3,190~6,600 | 3,190~6,600 | 국내 공개가 3,190원부터 |
| LRS-100-12 또는 동급 전원 | 1개, 12V/약100W 예산 후보 | 32,912~42,284 | 32,912~42,284 | RS/ICbanQ 판매가 참고 |
| 12V→5V DC-DC | 1개, FPGA·논리 전원 | 2,970~9,900 | 2,970~9,900 | 국내 모듈 공개가 참고 |
| 면별 10핀 IDC 신호 케이블 | 6개 / 8개, 20~30cm | 14,400~19,800 | 19,200~26,400 | 공개가 2,400~3,000원/개 + VAT 여유 |
| 전원 분배·퓨즈·스위치·전선 | 1식, 6갈래 / 8갈래 | 10,000~20,000 | 15,000~25,000 | 구성 미확정 자재 예비액 |
| FPGA 어댑터·클록 분배 자재 | 1식, 만능기판/헤더/필요 시 버퍼 | 20,000~50,000 | 20,000~50,000 | 직접 조립 자재 예비액 |
| 프레임·브래킷·스페이서·나사 | 소형 PoC 1식 | 50,000~100,000 | 60,000~120,000 | 기구 도면 미확정 예비액 |
| USB 전선·납·열수축 등 소모품 | 1식 | 10,000~20,000 | 10,000~20,000 | 예비액 |
| 추가 구매품 별도 배송 | FPGA 해외배송 및 국내 분할 배송 | 15,000~35,000 | 15,000~35,000 | 패널 배송과 별도 |
| **추가 구매 합계** | | **227,432~409,584** | **247,232~441,184** | 송신기 제외 |

12V/100W는 견적 비교용 전원 후보다. 실제 전압·전류 용량은 구동 파형과 소비전류 확인 후 정해야 하며 100W를 필수 소비전력으로 단정하지 않는다. LM2596류는 5V 논리 전원용 후보로 계산했다. 랑주뱅 발진기를 이 12V 전원이나 TC4427 출력에 연결하는 구성은 아니다.

정확한 헤더 핀 배열에 맞춰 어댑터가 필요하다. FPGA 보드를 사는 것만으로 새 패널용 펌웨어·ARM 제어가 완료되지 않는다. 이 예산의 2만~5만원은 직접 만드는 자재값이며 설계 외주 견적이 아니다.

### 추가 구매품의 판매처 링크

- [Waveshare CoreEP4CE6 공식 상품](https://www.waveshare.com/product/mcu-tools/core-boards-compact-boards/altera-core/coreep4ce6.htm): $38.99. 로컬 SonicSurface BOM에 지정된 보드. 다운로드 장치는 기본 구성에 포함되지 않는다.
- [디바이스마트 USB Blaster 호환 모듈](https://www.devicemart.co.kr/goods/view?no=1326947): 3,600원 / VAT 포함 3,960원.
- [디바이스마트 CP2102 Micro USB-TTL](https://www.devicemart.co.kr/goods/view?no=1326839): 2,900원 / VAT 포함 3,190원.
- [RS LRS-100-12](https://kr.rs-online.com/web/p/switching-power-supplies/1065844): 표시 29,920원, VAT 여유를 더한 32,912원을 하한 참고로 계산.
- [ICbanQ LRS-100-12](https://www.icbanq.com/P009899767): 38,440원 / VAT 포함 42,284원.
- [디바이스마트 LM2596 전압표시 모듈](https://www.devicemart.co.kr/goods/view?no=1321166): 2,700원 / VAT 포함 2,970원. [다른 국내 모듈 가격 참고](https://www.devicemart.co.kr/goods/brand?code=2487): 9,000원부터, VAT 별도.
- [스마트케이블 IDC 케이블](https://smartcable.co.kr/category/idc-%EB%8D%B0%EC%9D%B4%ED%84%B0-%ED%86%B5%EC%8B%A0-%EC%BC%80%EC%9D%B4%EB%B8%94/569/): 10핀 20cm 2,400원 / 30cm 3,000원. 실제 길이·배선 방향에 맞춰 선택.

## 4. 센서를 제외한 전체 구매·제작 예산

| 선택할 제작 경로 | 6면 / 6장(원) | 8면 / 8장(원) |
|---|---:|---:|
| 해외 제조·실장 + 추가 구매품 | **441,932~877,084** | **495,832~958,184** |
| 국내 제조·실장 + 추가 구매품 | **1,151,982~1,612,434** | **1,238,332~1,721,584** |

**센서 비용을 더한 합계는 사용자 요청대로 대화창에서만 제공한다.** 이미 보유한 FPGA·전원·프레임·케이블은 해당 금액을 뺀다. 부양력·운반 성능 검증을 완료한 완제품의 외주 납품 가격이 아니라 제작 및 구매 예산이다.

## 5. 참조 자료에서 반영한 내용 및 미확정 추가 범위

- `simulations/SonicSurface/Electronics/16x16 10mm transducers SMD PCB Gerbers/BOM.txt`: FPGA CoreEP4CE6 및 시프트 레지스터/듀얼 드라이버 구성의 근거. 기존 256채널 수량 대신 현 패널 수량을 적용했다.
- `simulations/SonicSurface/Firmware/README.md`: FPGA 다운로드 및 제어 펌웨어 필요성. ESP는 선택 사항이므로 기본 합계에서 제외.
- `자료조사/회의결과_및_수정사항.txt`: L298N 제외, 부양·선형 운반·고정으로 목표 변경, 하단 랑주뱅 하이브리드 후보. 카메라 스캔 시스템은 별도 검토 대상으로 분리되어 있어 이 견적에서도 제외.
- `자료조사/초음파부상 및 역장제어 자료조사.hwpx`: ZIP 내 XML을 읽어 기존 BOM을 확인했다. 기존 수량·드라이버·표시 가격을 현 설계에 그대로 적용하지 않았다.

랑주뱅 하이브리드의 트랜스듀서·전용 발진기·혼/방사판·고정구는 현 패널의 필수 부품이 아니다. 선택할 경우 별도 음향·구동 설계가 필요하다. 기존 문서의 60W 발진기 1개로 진동자 2개를 구동하는 수량을 확정 구성으로 사용하지 않았다. 송신기 관련 추가 가격은 대화에서만 설명한다.

기본 합계에 포함되지 않은 비용: FPGA 펌웨어 수정 및 어댑터 설계 외주, 실제 부양/운반 검증 엔지니어링, 정밀 가공 프레임, 랑주뱅 하이브리드, 카메라 스캔 시스템, PC, 새 납땜 공구·오실로스코프, 시제품 재제작. 작업을 외주 맡기는 경우 해당 범위를 별도 견적해야 한다.

## 신뢰도 및 검산

- **높음:** 기존 회로도 BOM 수량, PCB의 SMD/THT 구분 및 납땜 점수, 공임 곱셈·합계.
- **중간:** 조회 당시의 공개 업체 단가·판매가.
- **낮음~중간:** 최종 제조 패널 수, 해외 베어 PCB·배송비, 미설계 프레임·어댑터 자재의 예비액.
- 파일·납품 조건을 업체가 검토한 견적은 아직 없으며, 보고서의 상한은 실제 계약 가격의 상한을 보장하지 않는다.

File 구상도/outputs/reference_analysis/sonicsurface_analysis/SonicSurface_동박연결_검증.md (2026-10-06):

# SonicSurface 1.2 동박 연결 검증

검증일: 2026-10-02. 대상: Main.GTL, Main.GBL, Main.GTS, Main.TXT, Main.CSV, Pick Place for Main.txt 및 FPGA primary 소스.

후속 [원문 근거 대조](SonicSurface_원문근거_대조.md)에서 논문 Figure 2의 +5V 표기와 Figure 3의 동일 면 송신기 장착을 확인했다. 설계 의도의 논리 전압과 장착 방향은 문서로 확인되었으며, 실제 커넥터의 물리 핀 대응 및 실물 계측은 별도다.

## 검증 결과

상·하층 Gerber의 동박, clear 영역과 패드 형상을 복원하고, 도금 관통홀 좌표를 통해 두 층의 연결을 합쳤다. IC의 패드 위치는 부품 좌표표와 솔더마스크에 대조했다. 아래 결과는 **제조 파일에서 추적한 정적 연결 검증**이며 완제품 통전 시험이나 원본 CAD의 ERC/DRC는 아니다.

| 확인 항목 | 결과 |
|---|---|
| 부품 592개 패드의 동박 대응 | 대응하지 못한 패드 0개 |
| 시프트 레지스터 → 드라이버 입력 | **256/256 연결** |
| 드라이버 출력 → 송신기 단자 | **256/256 연결** |
| 송신기의 다른 단자 → 공통 GND | **256/256 연결** |
| 드라이버 GND 핀 | 128개 모두 공통 GND |
| 드라이버 전원 핀 | 128개 모두 동일 DRIVER_VDD 망 |
| 드라이버 핀 1·8 | 각각 128개 모두 다른 부품과 연결되지 않은 NC 패드 |
| 595의 출력 활성 /OE, 핀 13 | 32개 모두 GND에 고정 |
| 595의 리셋 /SRCLR, 핀 10 | 32개 모두 해당 논리 전원에 고정 |
| 논리 전원 | PCB 내부에서 서로 분리된 **2개 망**, 각각 24개와 8개의 595에 공급 |
| 드라이버 전원과 논리 전원, GND | 동박 추적상 서로 구분됨. 이 사이의 직접 단락은 찾지 않음 |
| 시프트 클록 / 래치 클록 | 각각 2개 망. 각 망은 595 16개의 해당 핀에 연결 |
| 드릴 좌표 | 1,505개, 드릴 보고서와 일치 |
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

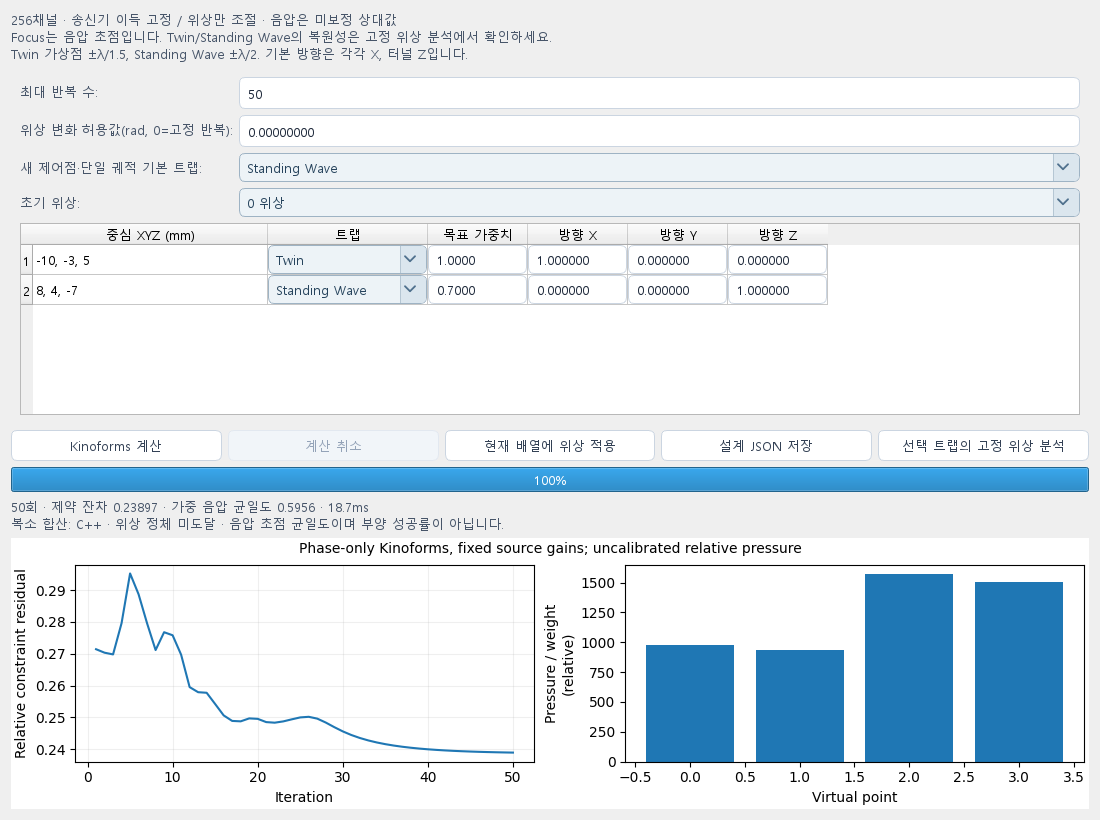
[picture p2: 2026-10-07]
scratch/ultraino_migration/t4_design_dialog.png

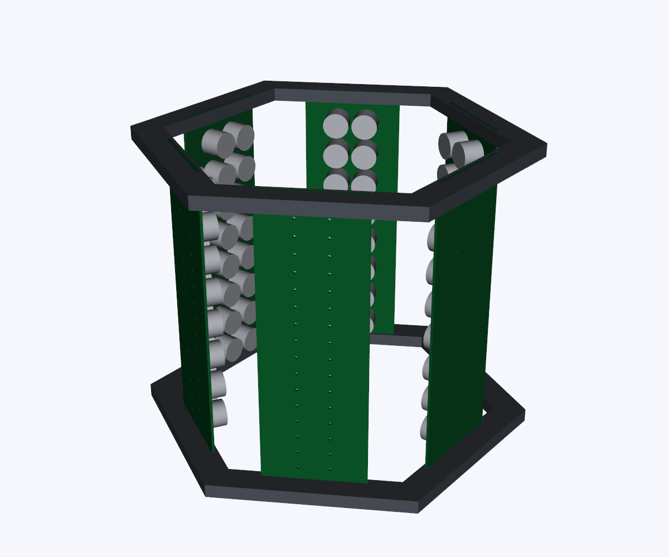
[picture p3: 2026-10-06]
구상도/creo_tunnel/v2_dual_panel/preview_6f.png

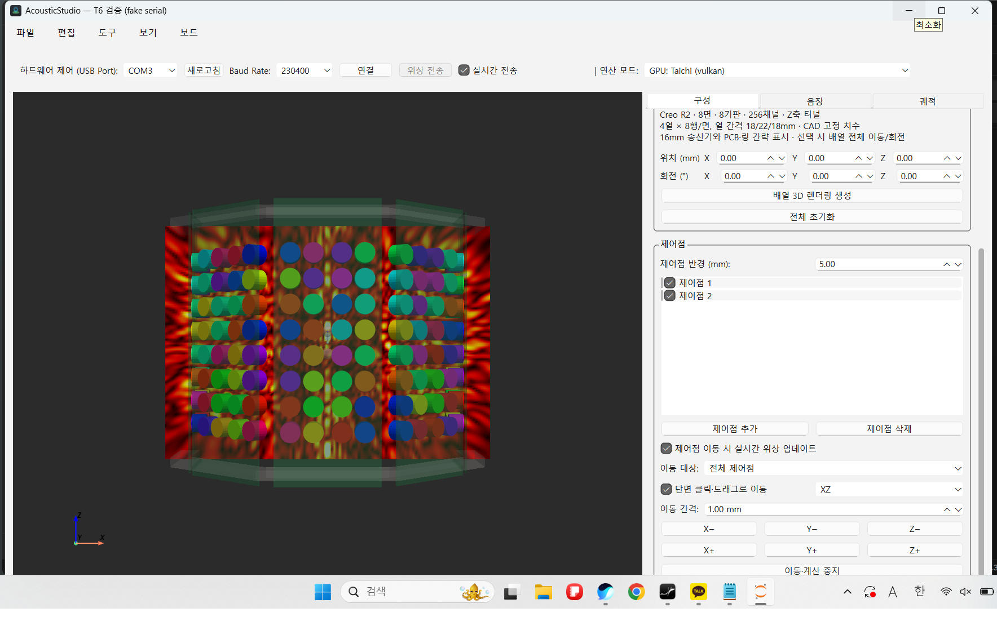
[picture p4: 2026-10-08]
scratch/ultraino_migration/t6_ui.png

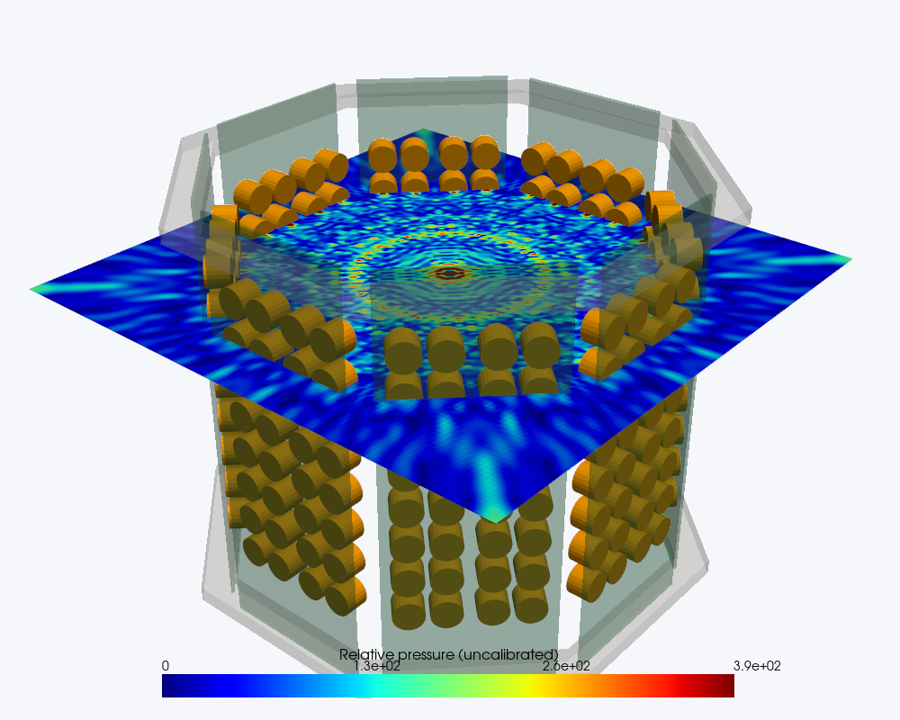
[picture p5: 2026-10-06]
scratch/ultraino_migration/t2_field_xy.png

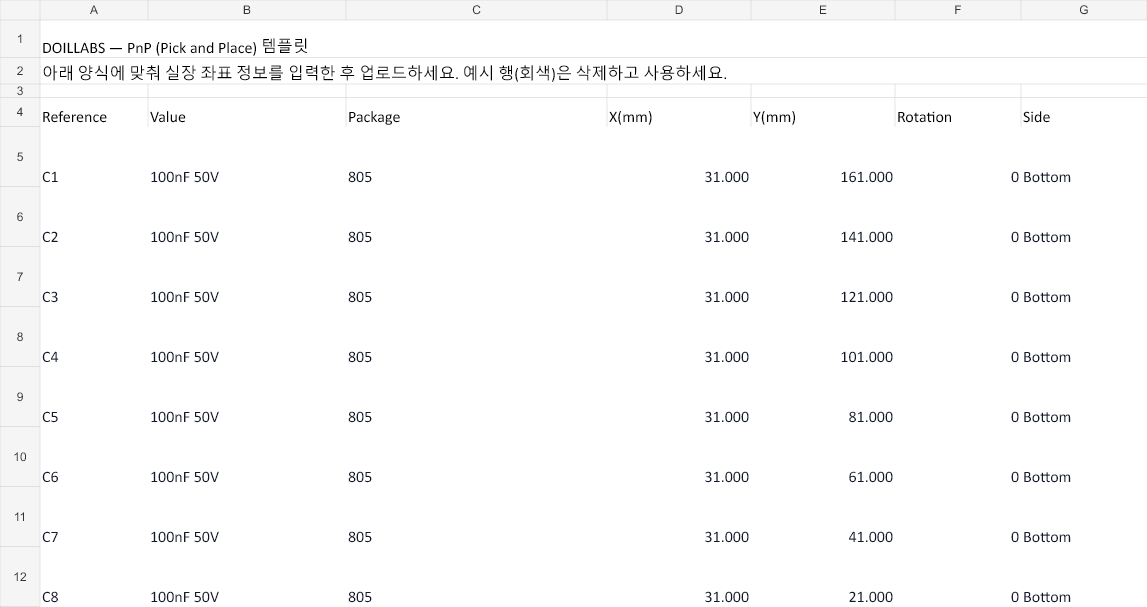
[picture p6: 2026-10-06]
구상도/scratch/pcba_artifact/doillabs_PnP.png

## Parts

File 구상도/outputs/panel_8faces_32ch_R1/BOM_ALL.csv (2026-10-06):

Designator | Value | Package | Qty_per_PCB | Qty_8_PCB | Assembly | Manufacturer | MPN_candidate | LCSC_candidate | Status
U1,U2,U3,U4 | 74HCT595D | SOIC-16 narrow 3.9mm | 4 | 32 | SMT | Nexperia | 74HCT595D,118 | C282339 | confirm exact part and availability before purchase
U5,U6,U7,U8,U9,U10,U11,U12,U13,U14,U15,U16,U17,U18,U19,U20 | TC4427A | SOIC-8 | 16 | 128 | SMT | Microchip | TC4427ACOA713 | C144234 | confirm exact part and availability before purchase
T1,T2,T3,T4,T5,T6,T7,T8,T9,T10,T11,T12,T13,T14,T15,T16,T17,T18,T19,T20,T21,T22,T23,T24,T25,T26,T27,T28,T29,T30,T31,T32 | V40AN16T | D16mm / pin pitch 10mm | 32 | 256 | THT |  |  |  | confirm exact part and availability before purchase
R1,R2,R3,R4,R5,R6,R7,R8,R9,R10,R11,R12,R13,R14,R15,R16,R17,R19,R26,R27,R28,R29,R30,R31,R32,R33,R34,R35,R36,R37,R38,R39,R40,R41,R42,R44 | 10k | 0805 | 36 | 288 | SMT | YAGEO | RC0805FR-0710KL |  | confirm exact part and availability before purchase
C1,C2,C3,C4,C5,C6,C7,C8,C21,C22,C23,C24,C25,C26,C27,C28 | 100nF 50V | 0805 | 16 | 128 | SMT | YAGEO | CC0805KRX7R9BB104 | C49678 | confirm exact part and availability before purchase
C11,C12,C13,C14,C15,C16,C17,C18,C31,C32,C33,C34,C35,C36,C37,C38 | 1uF 50V | 0805 | 16 | 128 | SMT | CCTC | TCC0805X7R105K500DT | C376926 | confirm exact part and availability before purchase
C9,C10,C29,C30 | 100nF 16V | 0805 | 4 | 32 | SMT | YAGEO | CC0805KRX7R9BB104 | C49678 | confirm exact part and availability before purchase
C19,C39 | 220uF 25V | Radial D6.3mm P2.5mm | 2 | 16 | THT | Rubycon | 25YXJ220M6.3X11 | C88729 | confirm exact part and availability before purchase
C20,C40 | 10uF 16V | 0805 | 2 | 16 | SMT | Murata | GRM21BR61E106KA73L |  | confirm exact part and availability before purchase
Q1,Q2 | MMBT3904 | SOT-23 | 2 | 16 | SMT | Nexperia | MMBT3904,215 |  | confirm exact part and availability before purchase
R18,R22,R23,R24,R25,R43,R47,R48,R49,R50 | 100k | 0805 | 10 | 80 | SMT | YAGEO | RC0805FR-07100KL |  | confirm exact part and availability before purchase
R20,R21,R45,R46 | 33R | 0805 | 4 | 32 | SMT | YAGEO | RC0805FR-0733RL |  | confirm exact part and availability before purchase
J1,J2 | FPGA_SIGNAL_3V3 | 2x5 2.54mm | 2 | 16 | THT |  |  |  | confirm exact part and availability before purchase
J3,J4 | POWER_INPUT | 1x3 2.54mm | 2 | 16 | THT |  |  |  | confirm exact part and availability before purchase

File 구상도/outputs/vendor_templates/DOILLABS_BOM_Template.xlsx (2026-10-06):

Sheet: BOM
DOILLABS — BOM (Bill of Materials) 템플릿
아래 양식에 맞춰 부품 정보를 입력한 후 업로드하세요. 예시 행(회색)은 삭제하고 사용하세요.
Reference | Value | Package | Quantity | Description | Manufacturer | MPN
R1 | 10K | 0402 | 1 | Chip Resistor
R2 | 4.7K | 0402 | 1 | Chip Resistor
R3 | 100 | 0603 | 2 | Chip Resistor
C1 | 100nF | 0402 | 1 | MLCC
C2 | 10uF | 0805 | 1 | MLCC | Samsung | CL21A106KPFNNNE
C3 | 22uF | 1206 | 1 | Tantalum
U1 | STM32F411 | LQFP-48 | 1 | MCU | ST | STM32F411CEU6
U2 | LM1117-3.3 | SOT-223 | 1 | LDO Regulator | TI | LM1117IMPX-3.3
D1 | LED-RED | 0603 | 2 | Indicator LED
J1 | USB-C | USB-C-16P | 1 | USB Connector
SW1 | TACT-SW | 6x6mm | 1 | Tact Switch (THT)

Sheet: 입력 안내
BOM 입력 안내
항목 | 필수 | 설명 | 예시
Reference | O | 부품 참조 번호 (Ref Des). 보드 위의 부품 식별자. | R1, C1, U1, J1
Value | O | 부품 값. 저항=옴, 캐패시터=패럿, IC=모델명. | 10K, 100nF, STM32F411
Package | O | 부품 패키지/풋프린트. SMT 실장 크기 결정에 사용. | 0402, 0805, LQFP-48, SOT-223
Quantity | O | 1보드 기준 해당 부품 수량. | 1, 2, 4
Description | - | 부품 설명 (선택). 분류 보조에 사용. | Chip Resistor, MCU
Manufacturer | - | 제조사 (선택). | Samsung, ST, TI
MPN | - | 제조사 부품 번호 (선택). | CL21A106KPFNNNE
패키지 분류 기준
분류 | 패키지 예시 | 설명
SMD | 0201, 0402, 0603, 0805, 1206, SOT-23, QFN | 표면 실장 (자동 리플로우)
Fine Pitch | 0201, 01005 | 미세피치 — 추가 비용 발생
BGA | BGA-256, FBGA-96 | Ball Grid Array — X-Ray 검사 필요
THT | DIP, TO-220, 6x6mm | Through Hole — 수삽 비용 발생
지원 형식: CSV, TSV, Excel (.xlsx/.xls)
인코딩: UTF-8 권장 (한글 호환)

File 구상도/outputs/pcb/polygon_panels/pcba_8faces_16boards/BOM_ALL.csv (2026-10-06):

Comment | Designator | Footprint | Manufacturer | MPN | LCSC Part # | Quantity
100nF 50V X7R 10% 0805 | C1,C2,C3,C4,C5,C6,C7,C8,C9,C10 | C0805 | YAGEO | CC0805KRX7R9BB104 | C49678 | 10
1uF 50V X7R 10% 0805 | C11,C12,C13,C14,C15,C16,C17,C18 | C0805 | CCTC | TCC0805X7R105K500DT | C376926 | 8
10uF >=16V 0805 | C20 | C0805 | Murata | GRM21BR61E106KA73L |  | 1
220uF 25V radial D6.3mm P2.5mm | C19 | CP_Radial_D6.3_P2.5 | Rubycon | 25YXJ220M6.3X11 | C88729 | 1
10k 1% 0805 0.125W | R1,R2,R3,R4,R5,R6,R7,R8,R9,R10,R11,R12,R13,R14,R15,R16,R17,R19 | R0805 | YAGEO | RC0805FR-0710KL |  | 18
100k 1% 0805 0.125W | R18,R22,R23,R24,R25 | R0805 | YAGEO | RC0805FR-07100KL |  | 5
33 ohm 1% 0805 0.125W | R20,R21 | R0805 | YAGEO | RC0805FR-0733RL |  | 2
74HCT595 SO16 shift register | U1,U2 | SOIC16 | Nexperia | 74HCT595D,118 | C282339 | 2
TC4427A dual non-inverting driver SOIC8 | U3,U4,U5,U6,U7,U8,U9,U10 | SOIC8 | Microchip | TC4427ACOA713 | C144234 | 8
MMBT3904 NPN SOT23 | Q1 | SOT23 | Nexperia | MMBT3904,215 |  | 1
Male straight header 2x5 P2.54mm | J1 | Header2x05 | Vendor selection |  |  | 1
Male straight header 1x3 P2.54mm | J2 | Header1x03 | Vendor selection |  |  | 1
40kHz transmitter D16mm pin pitch 10mm | T1,T2,T3,T4,T5,T6,T7,T8,T9,T10,T11,T12,T13,T14,T15,T16 | V40AN16T_P10 | Supplier confirmation |  |  | 16

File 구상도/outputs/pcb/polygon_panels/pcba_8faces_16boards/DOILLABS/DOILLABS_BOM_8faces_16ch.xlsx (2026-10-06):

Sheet: BOM
DOILLABS — BOM (Bill of Materials) 템플릿
아래 양식에 맞춰 부품 정보를 입력한 후 업로드하세요. 예시 행(회색)은 삭제하고 사용하세요.
Reference | Value | Package | Quantity | Description | Manufacturer | MPN
C1 | 100nF 50V | 0805 | 1 | SMT: 100nF 50V X7R 10% 0805 | YAGEO | CC0805KRX7R9BB104
C2 | 100nF 50V | 0805 | 1 | SMT: 100nF 50V X7R 10% 0805 | YAGEO | CC0805KRX7R9BB104
C3 | 100nF 50V | 0805 | 1 | SMT: 100nF 50V X7R 10% 0805 | YAGEO | CC0805KRX7R9BB104
C4 | 100nF 50V | 0805 | 1 | SMT: 100nF 50V X7R 10% 0805 | YAGEO | CC0805KRX7R9BB104
C5 | 100nF 50V | 0805 | 1 | SMT: 100nF 50V X7R 10% 0805 | YAGEO | CC0805KRX7R9BB104
C6 | 100nF 50V | 0805 | 1 | SMT: 100nF 50V X7R 10% 0805 | YAGEO | CC0805KRX7R9BB104
C7 | 100nF 50V | 0805 | 1 | SMT: 100nF 50V X7R 10% 0805 | YAGEO | CC0805KRX7R9BB104
C8 | 100nF 50V | 0805 | 1 | SMT: 100nF 50V X7R 10% 0805 | YAGEO | CC0805KRX7R9BB104
C9 | 100nF 50V | 0805 | 1 | SMT: 100nF 50V X7R 10% 0805 | YAGEO | CC0805KRX7R9BB104
C10 | 100nF 50V | 0805 | 1 | SMT: 100nF 50V X7R 10% 0805 | YAGEO | CC0805KRX7R9BB104
C11 | 1uF 50V | 0805 | 1 | SMT: 1uF 50V X7R 10% 0805 | CCTC | TCC0805X7R105K500DT
C12 | 1uF 50V | 0805 | 1 | SMT: 1uF 50V X7R 10% 0805 | CCTC | TCC0805X7R105K500DT
C13 | 1uF 50V | 0805 | 1 | SMT: 1uF 50V X7R 10% 0805 | CCTC | TCC0805X7R105K500DT
C14 | 1uF 50V | 0805 | 1 | SMT: 1uF 50V X7R 10% 0805 | CCTC | TCC0805X7R105K500DT
C15 | 1uF 50V | 0805 | 1 | SMT: 1uF 50V X7R 10% 0805 | CCTC | TCC0805X7R105K500DT
C16 | 1uF 50V | 0805 | 1 | SMT: 1uF 50V X7R 10% 0805 | CCTC | TCC0805X7R105K500DT
C17 | 1uF 50V | 0805 | 1 | SMT: 1uF 50V X7R 10% 0805 | CCTC | TCC0805X7R105K500DT
C18 | 1uF 50V | 0805 | 1 | SMT: 1uF 50V X7R 10% 0805 | CCTC | TCC0805X7R105K500DT
C19 | 220uF 25V | Radial D6.3 P2.5 (THT) | 1 | THT hand solder: 220uF 25V radial D6.3mm P2.5mm | Rubycon | 25YXJ220M6.3X11
C20 | 10uF >=16V | 0805 | 1 | SMT: 10uF >=16V 0805 | Murata | GRM21BR61E106KA73L
J1 | FPGA_SIGNAL_3V3 | 2x5 P2.54 (THT) | 1 | THT hand solder: Male straight header 2x5 P2.54mm
J2 | POWER_INPUT | 1x3 P2.54 (THT) | 1 | THT hand solder: Male straight header 1x3 P2.54mm
Q1 | MMBT3904 | SOT-23 | 1 | SMT: MMBT3904 NPN SOT23 | Nexperia | MMBT3904,215
R1 | 10k | 0805 | 1 | SMT: 10k 1% 0805 0.125W | YAGEO | RC0805FR-0710KL
R2 | 10k | 0805 | 1 | SMT: 10k 1% 0805 0.125W | YAGEO | RC0805FR-0710KL
R3 | 10k | 0805 | 1 | SMT: 10k 1% 0805 0.125W | YAGEO | RC0805FR-0710KL
R4 | 10k | 0805 | 1 | SMT: 10k 1% 0805 0.125W | YAGEO | RC0805FR-0710KL
R5 | 10k | 0805 | 1 | SMT: 10k 1% 0805 0.125W | YAGEO | RC0805FR-0710KL
R6 | 10k | 0805 | 1 | SMT: 10k 1% 0805 0.125W | YAGEO | RC0805FR-0710KL
R7 | 10k | 0805 | 1 | SMT: 10k 1% 0805 0.125W | YAGEO | RC0805FR-0710KL
R8 | 10k | 0805 | 1 | SMT: 10k 1% 0805 0.125W | YAGEO | RC0805FR-0710KL
R9 | 10k | 0805 | 1 | SMT: 10k 1% 0805 0.125W | YAGEO | RC0805FR-0710KL
R10 | 10k | 0805 | 1 | SMT: 10k 1% 0805 0.125W | YAGEO | RC0805FR-0710KL
R11 | 10k | 0805 | 1 | SMT: 10k 1% 0805 0.125W | YAGEO | RC0805FR-0710KL
R12 | 10k | 0805 | 1 | SMT: 10k 1% 0805 0.125W | YAGEO | RC0805FR-0710KL
R13 | 10k | 0805 | 1 | SMT: 10k 1% 0805 0.125W | YAGEO | RC0805FR-0710KL
R14 | 10k | 0805 | 1 | SMT: 10k 1% 0805 0.125W | YAGEO | RC0805FR-0710KL
R15 | 10k | 0805 | 1 | SMT: 10k 1% 0805 0.125W | YAGEO | RC0805FR-0710KL
R16 | 10k | 0805 | 1 | SMT: 10k 1% 0805 0.125W | YAGEO | RC0805FR-0710KL
R17 | 10k | 0805 | 1 | SMT: 10k 1% 0805 0.125W | YAGEO | RC0805FR-0710KL
R18 | 100k | 0805 | 1 | SMT: 100k 1% 0805 0.125W | YAGEO | RC0805FR-07100KL
R19 | 10k | 0805 | 1 | SMT: 10k 1% 0805 0.125W | YAGEO | RC0805FR-0710KL
R20 | 33R | 0805 | 1 | SMT: 33 ohm 1% 0805 0.125W | YAGEO | RC0805FR-0733RL
R21 | 33R | 0805 | 1 | SMT: 33 ohm 1% 0805 0.125W | YAGEO | RC0805FR-0733RL
R22 | 100k | 0805 | 1 | SMT: 100k 1% 0805 0.125W | YAGEO | RC0805FR-07100KL
R23 | 100k | 0805 | 1 | SMT: 100k 1% 0805 0.125W | YAGEO | RC0805FR-07100KL
R24 | 100k | 0805 | 1 | SMT: 100k 1% 0805 0.125W | YAGEO | RC0805FR-07100KL
R25 | 100k | 0805 | 1 | SMT: 100k 1% 0805 0.125W | YAGEO | RC0805FR-07100KL
T1 | V40AN16T | D16 P10 (THT) | 1 | THT hand solder: 40kHz transmitter D16mm pin pitch 10mm / manufacturer and phase polarity confirmation required
T2 | V40AN16T | D16 P10 (THT) | 1 | THT hand solder: 40kHz transmitter D16mm pin pitch 10mm / manufacturer and phase polarity confirmation required
T3 | V40AN16T | D16 P10 (THT) | 1 | THT hand solder: 40kHz transmitter D16mm pin pitch 10mm / manufacturer and phase polarity confirmation required
T4 | V40AN16T | D16 P10 (THT) | 1 | THT hand solder: 40kHz transmitter D16mm pin pitch 10mm / manufacturer and phase polarity confirmation required
T5 | V40AN16T | D16 P10 (THT) | 1 | THT hand solder: 40kHz transmitter D16mm pin pitch 10mm / manufacturer and phase polarity confirmation required
T6 | V40AN16T | D16 P10 (THT) | 1 | THT hand solder: 40kHz transmitter D16mm pin pitch 10mm / manufacturer and phase polarity confirmation required
T7 | V40AN16T | D16 P10 (THT) | 1 | THT hand solder: 40kHz transmitter D16mm pin pitch 10mm / manufacturer and phase polarity confirmation required
T8 | V40AN16T | D16 P10 (THT) | 1 | THT hand solder: 40kHz transmitter D16mm pin pitch 10mm / manufacturer and phase polarity confirmation required
T9 | V40AN16T | D16 P10 (THT) | 1 | THT hand solder: 40kHz transmitter D16mm pin pitch 10mm / manufacturer and phase polarity confirmation required
T10 | V40AN16T | D16 P10 (THT) | 1 | THT hand solder: 40kHz transmitter D16mm pin pitch 10mm / manufacturer and phase polarity confirmation required
T11 | V40AN16T | D16 P10 (THT) | 1 | THT hand solder: 40kHz transmitter D16mm pin pitch 10mm / manufacturer and phase polarity confirmation required
T12 | V40AN16T | D16 P10 (THT) | 1 | THT hand solder: 40kHz transmitter D16mm pin pitch 10mm / manufacturer and phase polarity confirmation required
T13 | V40AN16T | D16 P10 (THT) | 1 | THT hand solder: 40kHz transmitter D16mm pin pitch 10mm / manufacturer and phase polarity confirmation required
T14 | V40AN16T | D16 P10 (THT) | 1 | THT hand solder: 40kHz transmitter D16mm pin pitch 10mm / manufacturer and phase polarity confirmation required
T15 | V40AN16T | D16 P10 (THT) | 1 | THT hand solder: 40kHz transmitter D16mm pin pitch 10mm / manufacturer and phase polarity confirmation required
T16 | V40AN16T | D16 P10 (THT) | 1 | THT hand solder: 40kHz transmitter D16mm pin pitch 10mm / manufacturer and phase polarity confirmation required
U1 | 74HCT595D | SOIC-16 | 1 | SMT: 74HCT595 SO16 shift register | Nexperia | 74HCT595D,118
U2 | 74HCT595D | SOIC-16 | 1 | SMT: 74HCT595 SO16 shift register | Nexperia | 74HCT595D,118
U3 | TC4427A | SOIC-8 | 1 | SMT: TC4427A dual non-inverting driver SOIC8 | Microchip | TC4427ACOA713
U4 | TC4427A | SOIC-8 | 1 | SMT: TC4427A dual non-inverting driver SOIC8 | Microchip | TC4427ACOA713
U5 | TC4427A | SOIC-8 | 1 | SMT: TC4427A dual non-inverting driver SOIC8 | Microchip | TC4427ACOA713
U6 | TC4427A | SOIC-8 | 1 | SMT: TC4427A dual non-inverting driver SOIC8 | Microchip | TC4427ACOA713
U7 | TC4427A | SOIC-8 | 1 | SMT: TC4427A dual non-inverting driver SOIC8 | Microchip | TC4427ACOA713
U8 | TC4427A | SOIC-8 | 1 | SMT: TC4427A dual non-inverting driver SOIC8 | Microchip | TC4427ACOA713
U9 | TC4427A | SOIC-8 | 1 | SMT: TC4427A dual non-inverting driver SOIC8 | Microchip | TC4427ACOA713
U10 | TC4427A | SOIC-8 | 1 | SMT: TC4427A dual non-inverting driver SOIC8 | Microchip | TC4427ACOA713

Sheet: 입력 안내
BOM 입력 안내
항목 | 필수 | 설명 | 예시
Reference | O | 부품 참조 번호 (Ref Des). 보드 위의 부품 식별자. | R1, C1, U1, J1
Value | O | 부품 값. 저항=옴, 캐패시터=패럿, IC=모델명. | 10K, 100nF, STM32F411
Package | O | 부품 패키지/풋프린트. SMT 실장 크기 결정에 사용. | 0402, 0805, LQFP-48, SOT-223
Quantity | O | 1보드 기준 해당 부품 수량. | 1, 2, 4
Description | - | 부품 설명 (선택). 분류 보조에 사용. | Chip Resistor, MCU
Manufacturer | - | 제조사 (선택). | Samsung, ST, TI
MPN | - | 제조사 부품 번호 (선택). | CL21A106KPFNNNE
패키지 분류 기준
분류 | 패키지 예시 | 설명
SMD | 0201, 0402, 0603, 0805, 1206, SOT-23, QFN | 표면 실장 (자동 리플로우)
Fine Pitch | 0201, 01005 | 미세피치 — 추가 비용 발생
BGA | BGA-256, FBGA-96 | Ball Grid Array — X-Ray 검사 필요
THT | DIP, TO-220, 6x6mm | Through Hole — 수삽 비용 발생
지원 형식: CSV, TSV, Excel (.xlsx/.xls)
인코딩: UTF-8 권장 (한글 호환)
이 파일은 한 보드 기준 74개 부품입니다. 16장 제작 수량은 주문 화면에서 설정합니다.
SMT 55개 + THT 19개. Description의 THT hand solder 항목은 별도 수삽 납땜 견적을 요청하세요.
U1/U2 구매 후보: Nexperia 74HCT595D,118 (SOIC-16). 원본 표시 SN74HCT595D를 대체하는 후보입니다.
트랜스듀서와 헤더의 정확한 제조사/MPN은 업체 확인이 필요하여 공란으로 남겼습니다.
견적용 초안. 기존 0.002 mm 간격 경고와 부품 매칭을 확인한 후 제조 승인하세요.

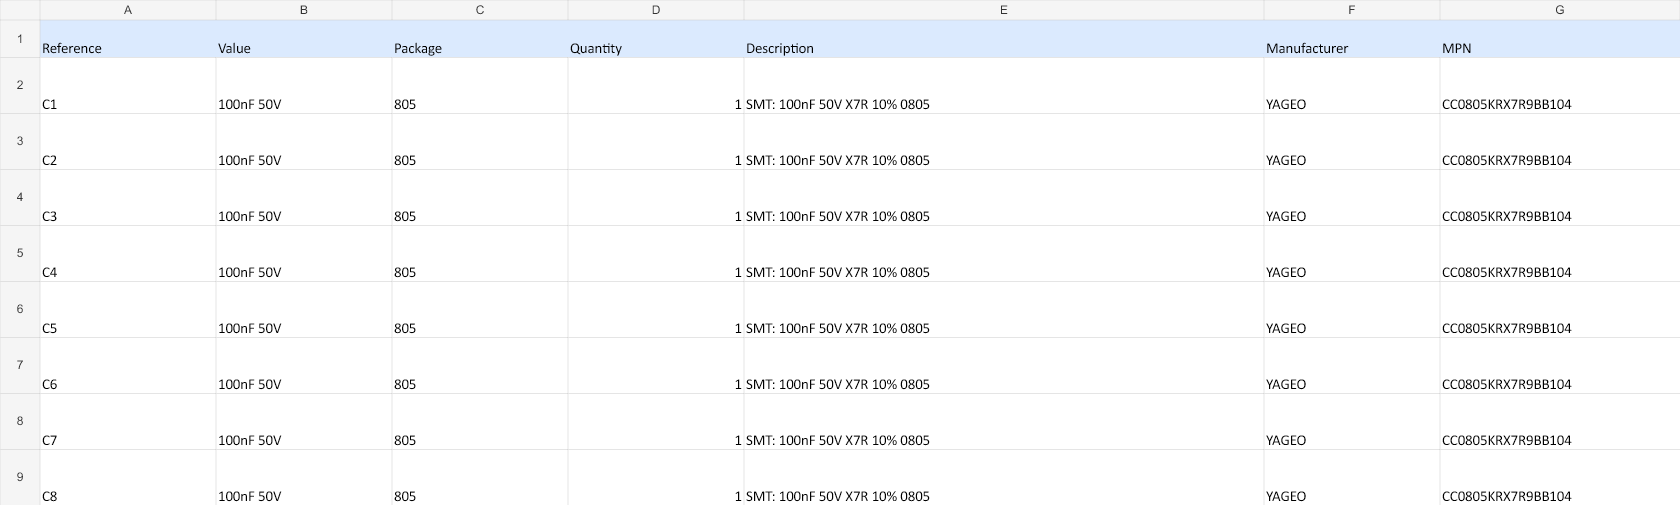
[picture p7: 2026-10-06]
구상도/scratch/pcba_artifact/doillabs_BOM_UPLOAD.png

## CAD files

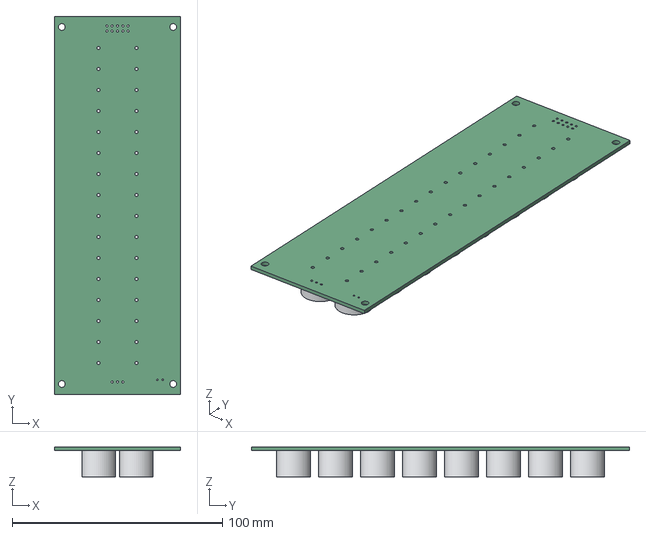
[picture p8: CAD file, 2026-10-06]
구상도/creo_tunnel/v1_single_panel/6faces/panel_6f.step
60.0 x 180.0 x 14.1 mm
pcb_6f
tx_6f_t1 x 16

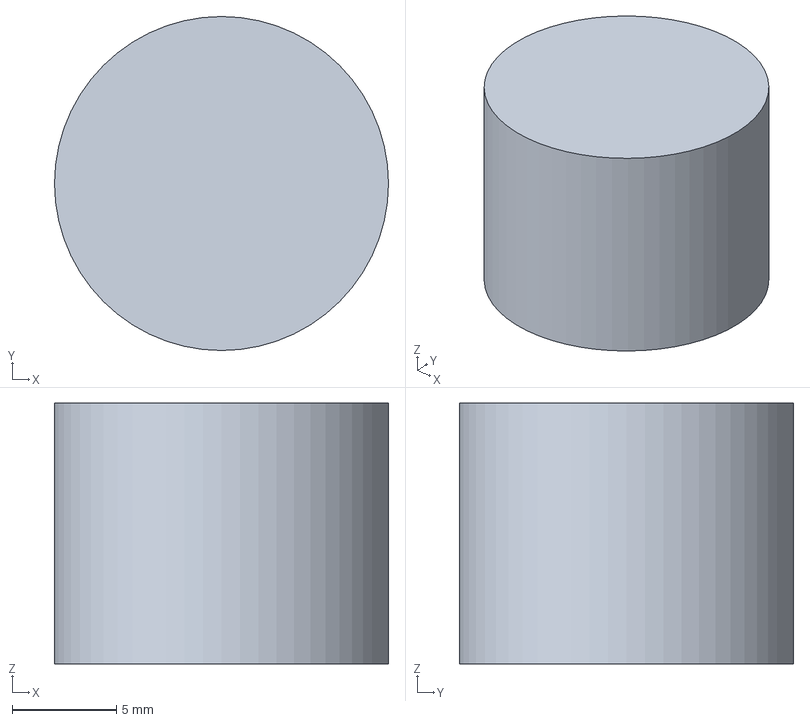
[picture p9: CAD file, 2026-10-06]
구상도/creo_tunnel/v1_single_panel/8faces/transducer_8f.step
16.0 x 16.0 x 12.5 mm

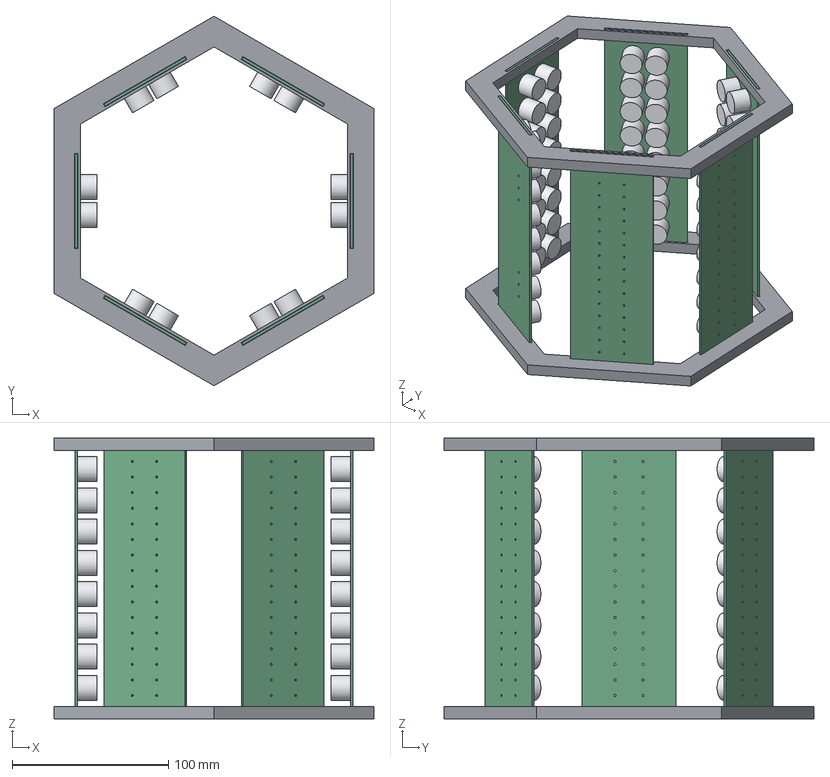
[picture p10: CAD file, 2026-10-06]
구상도/creo_tunnel/v2_dual_panel/geometry/tunnel_6f_v2.step
205.0 x 236.7 x 180.0 mm
pcb_6f x 6
tx_T1 x 96
ring_0 x 2

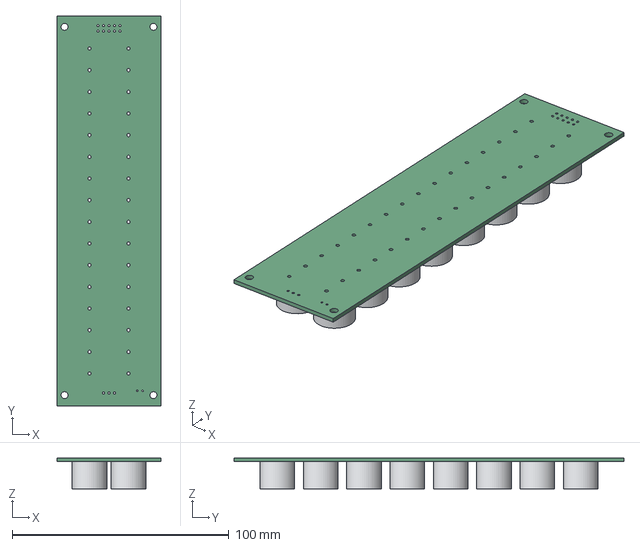
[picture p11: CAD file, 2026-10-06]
구상도/outputs/cad_generation/creo_tunnel_models/8faces/panel_8f.step
48.0 x 180.0 x 14.1 mm
pcb_8f
tx_8f_t1 x 16

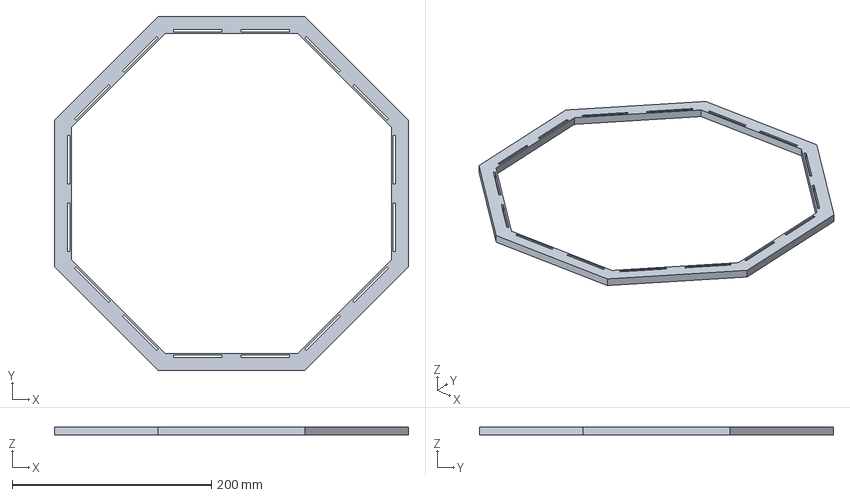
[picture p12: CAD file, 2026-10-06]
구상도/outputs/cad_generation/creo_tunnel_reused_v2/geometry/ring_8f.step
355.0 x 355.0 x 8.00 mm

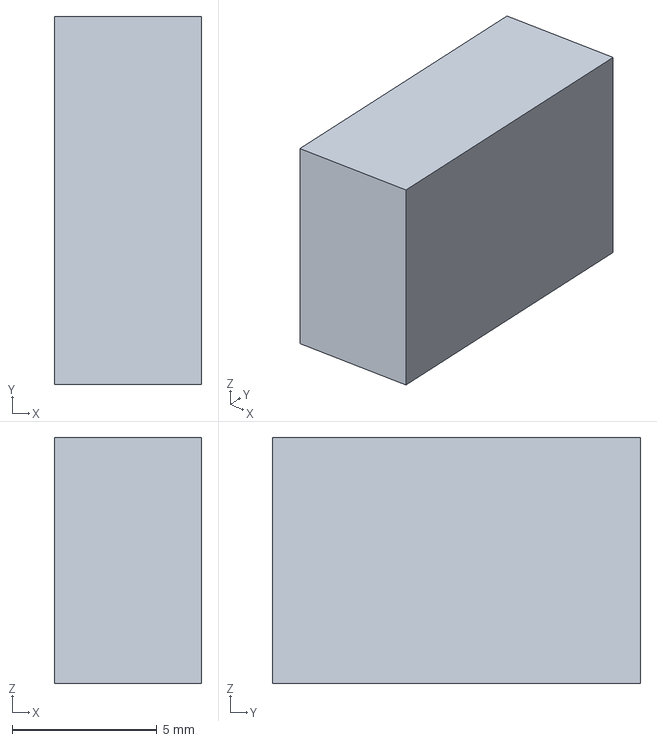
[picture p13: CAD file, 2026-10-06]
구상도/outputs/panel_8faces_32ch_R1/mechanical/creo32_frame_R2/validation/native_reexport/hdr10_r1.stp
5.08 x 12.7 x 8.50 mm

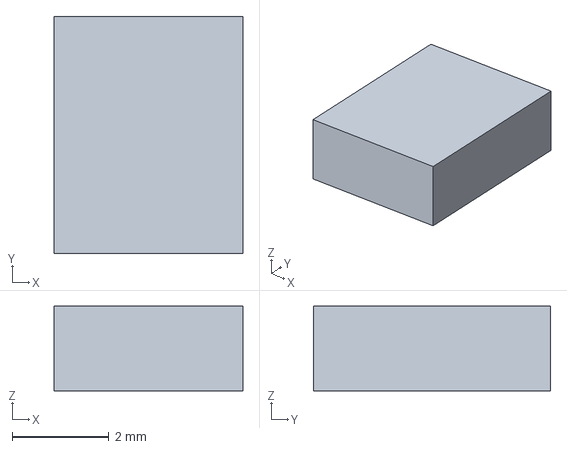
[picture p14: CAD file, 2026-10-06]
구상도/outputs/panel_8faces_32ch_R1/mechanical/creo32_R1/geometry/so8_r1.step
3.90 x 4.90 x 1.75 mm

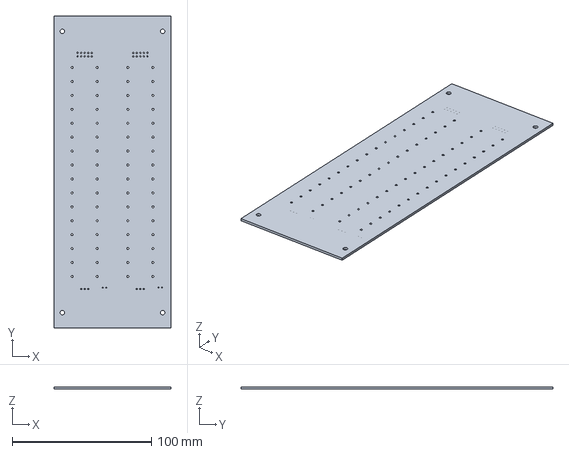
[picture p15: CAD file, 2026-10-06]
구상도/outputs/panel_8faces_32ch_R1/mechanical/creo32_R1/validation/native_reexport/pcb32_r1.stp
84.0 x 224.0 x 1.60 mm

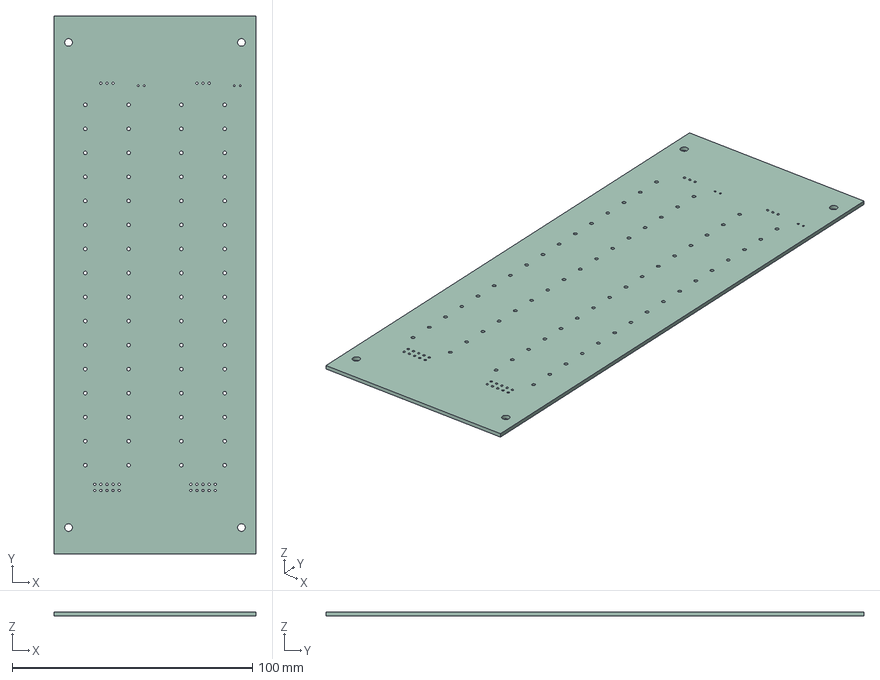
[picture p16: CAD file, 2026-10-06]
구상도/outputs/panel_8faces_32ch_R1/mechanical/panel_board_only.step
84.0 x 224.0 x 1.51 mm

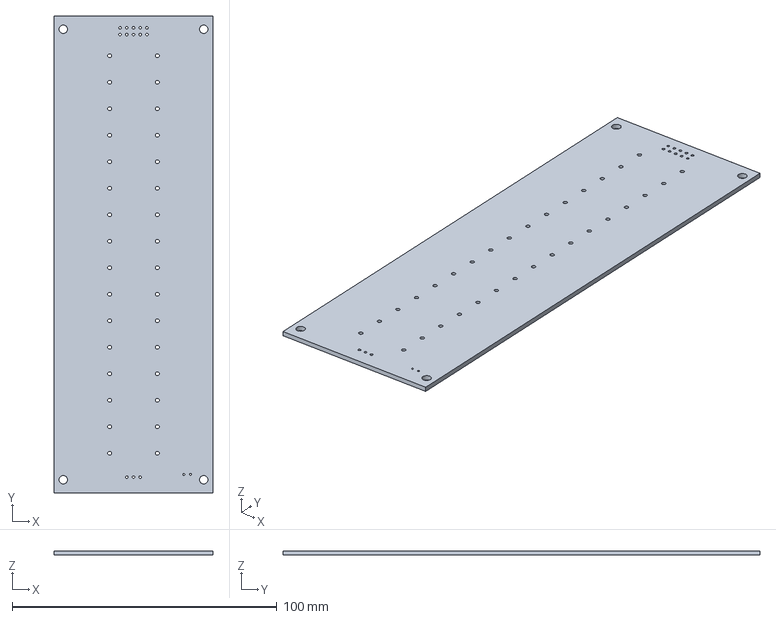
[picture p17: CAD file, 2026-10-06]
구상도/creo_tunnel/v1_single_panel/6faces/pcb_6f.step
60.0 x 180.0 x 1.60 mm

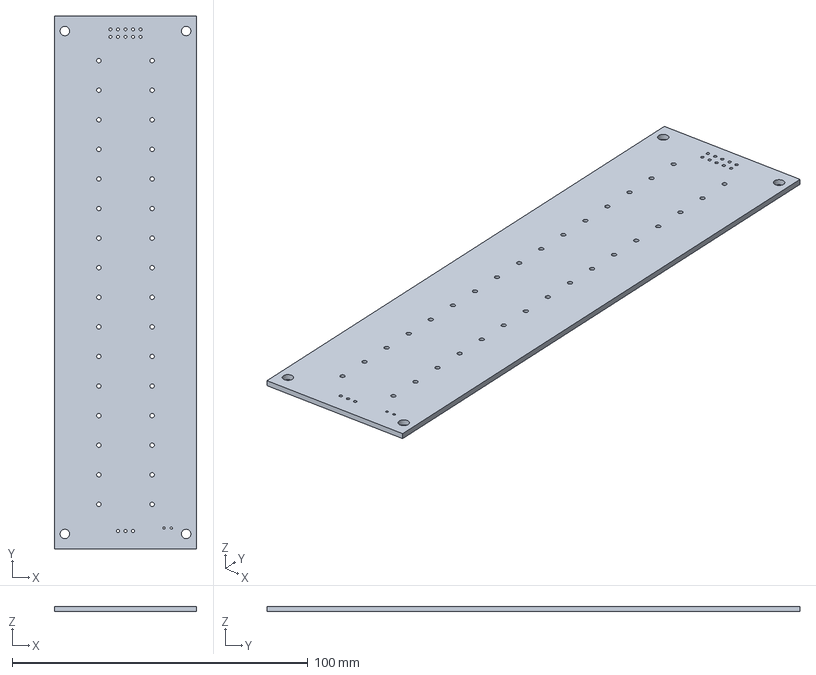
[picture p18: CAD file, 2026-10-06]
구상도/creo_tunnel/v1_single_panel/8faces/pcb_8f.step
48.0 x 180.0 x 1.60 mm

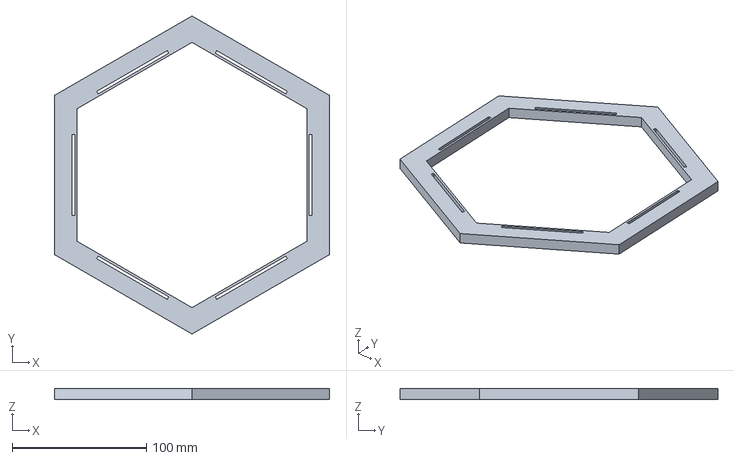
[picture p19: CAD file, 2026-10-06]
구상도/outputs/cad_generation/creo_tunnel_reused_v2/geometry/ring_6f.step
205.0 x 236.7 x 8.00 mm

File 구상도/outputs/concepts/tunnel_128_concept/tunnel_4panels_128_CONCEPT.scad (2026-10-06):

// CONCEPT ONLY. No manufacturing approval, mounting hardware or PCB copper.
// Coordinates: tunnel axis Z; inward acoustic normals; channel p*32+c*8+j.
face_diameter = 100;
active_length = 160;
gap_arc_at_face = 8;
emitter_diameter = 16;
emitter_body_height = 12.5;
frame_thickness = 2;
seat_clearance = 0.4;
show_emitters = true;
show_ideal_flex_reference = false; // Smooth surface ONLY; real pads need flat stiffened islands.
$fn = 64;
R = face_diameter/2;
rear_R = R + emitter_body_height;
half_gap_deg = gap_arc_at_face/(2*R)*180/PI;
span_deg = 90 - 2*half_gap_deg;
module sector(r1,r2,p) {
  rotate([0,0,p*90+half_gap_deg])
    rotate_extrude(angle=span_deg,convexity=10)
      translate([r1,0]) square([r2-r1,active_length]);
}
module radial_body(a,z,r,d,h) {
  translate([r*cos(a),r*sin(a),z]) rotate([0,0,a]) rotate([0,90,0]) cylinder(d=d,h=h);
}
for (p=[0:3]) {
  color([0.55,0.60,0.65]) difference() {
    sector(rear_R-frame_thickness,rear_R,p);
    for(c=[0:3],j=[0:7])
      radial_body(p*90+half_gap_deg+(c+0.5)*span_deg/4,
        (j+0.5)*active_length/8,R-1,emitter_diameter+seat_clearance,emitter_body_height+3);
  }
  if(show_emitters) for(c=[0:3],j=[0:7]) {
    a=p*90+half_gap_deg+(c+0.5)*span_deg/4;
    z=(j+0.5)*active_length/8;
    color([0.76,0.77,0.78]) radial_body(a,z,R,emitter_diameter,emitter_body_height);
    color([0.86,0.69,0.30]) radial_body(a,z,R-0.05,emitter_diameter-1,0.1);
  }
  if(show_ideal_flex_reference) color([0.9,0.45,0.1,0.35]) sector(rear_R,rear_R+0.2,p);
}

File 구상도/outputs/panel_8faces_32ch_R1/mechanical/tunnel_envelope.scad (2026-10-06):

// Concept envelope, not an external frame design. Dimensions in mm.
// PCB board-only STEP in the same directory is the native board outline.
$fn=40;
w=84; length=224; thickness=1.6; separation=210; tx_h=12.5; tx_d=16;
for(face=[0:7]) rotate([0,0,face*45]) {
  color([0.12,0.4,0.28,0.5]) difference() {
    translate([separation/2+tx_h,-w/2,-length/2]) cube([thickness,w,length]);
    for(xx=[6,w-6],yy=[11,length-11]) translate([separation/2+tx_h-1,xx-w/2,yy-length/2]) rotate([0,90,0]) cylinder(h=thickness+2,d=3.2);
  }
  for(col=[-29,-11,11,29],row=[0:7]) color([0.6,0.65,0.7]) translate([separation/2,col,42+row*20-length/2]) rotate([0,90,0]) cylinder(h=tx_h,d=tx_d);
}

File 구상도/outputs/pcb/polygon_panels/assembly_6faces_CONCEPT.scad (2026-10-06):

// CONCEPT assembly. Frame mounting/cable clearance is not final.
faces=6; panel_width=60; board_length=180;
face_apothem=75; body_height=12.5; board_thickness=1.6;
$fn=48;
module polygon_prism(apothem,h) {
  linear_extrude(height=h) polygon([for(i=[0:faces-1])
    [apothem/cos(180/faces)*cos((i+0.5)*360/faces),
     apothem/cos(180/faces)*sin((i+0.5)*360/faces)]]);
}
module end_ring(z) { translate([0,0,z]) difference() {
  polygon_prism(face_apothem+body_height+15,8);
  translate([0,0,-1]) polygon_prism(face_apothem+body_height-2,10);
} }
for(p=[0:faces-1]) rotate([0,0,p*360/faces]) {
  color([0.1,0.4,0.2]) translate([face_apothem+body_height,-panel_width/2,0])
    cube([board_thickness,panel_width,board_length]);
  for(r=[0:7],c=[0:1])
    color([0.7,0.7,0.72]) translate([face_apothem,(c-0.5)*18,20+r*20])
      rotate([0,90,0]) cylinder(d=16,h=body_height);
}
color([0.45,0.48,0.5]) {end_ring(0);end_ring(board_length-8);}

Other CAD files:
구상도/outputs/cad_generation/creo_tunnel_models/6faces/transducer_6f.step
구상도/outputs/panel_8faces_32ch_R1/mechanical/creo32_frame_R2/geometry/tx16_r1.step
구상도/outputs/panel_8faces_32ch_R1/mechanical/creo32_frame_R2/geometry/so8_r1.step
구상도/outputs/pcb/polygon_panels/assembly_8faces_CONCEPT.scad
구상도/creo_tunnel/v1_single_panel/6faces/native/pcb_6f.prt
구상도/creo_tunnel/v1_single_panel/6faces/native/ring_6f_lower.prt
구상도/creo_tunnel/v1_single_panel/6faces/native/tx_6f_t1.prt
구상도/creo_tunnel/v1_single_panel/6faces/ring_6f.step
구상도/creo_tunnel/v1_single_panel/6faces/transducer_6f.step
구상도/creo_tunnel/v1_single_panel/6faces/tunnel_6faces.step
구상도/creo_tunnel/v1_single_panel/8faces/native/pcb_8f.prt
구상도/creo_tunnel/v1_single_panel/8faces/native/ring_8f_lower.prt
구상도/creo_tunnel/v1_single_panel/8faces/native/tx_8f_t1.prt
구상도/creo_tunnel/v1_single_panel/8faces/ring_8f.step
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

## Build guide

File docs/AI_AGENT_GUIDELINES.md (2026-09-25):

# AI 에이전트 코드 수정 및 백업 가이드라인 (AI Agent Guidelines)

**모든 AI 에이전트(서브에이전트 포함)는 이 프로젝트의 코드를 수정할 때 반드시 아래의 프로세스를 준수해야 합니다.**

## 1. 작업 환경 및 필수 AI 스킬 점검 (Environment & Required Skills Check)
새로운 작업 환경(PC)에서 프로젝트를 Clone 또는 Pull 하여 AI 에이전트가 작업에 시작할때 코드 작업을 진행하기에 앞서 가장 먼저 다음 사항들을 필수로 점검해야 합니다.
- **실행 환경(Python) 점검**: 프로젝트 요구사항에 맞는 파이썬 버전이 설치되어 있는지 점검하고, 필요한 라이브러리(`requirements.txt`)가 모두 설치되어 있는지 확인합니다. 누락된 라이브러리가 있다면 본격적인 작업 전에 미리 다운로드 및 설치를 완료하십시오.
- **필수 AI 스킬 확인**: 로컬 환경에 **`karpathy-guidelines`** 스킬이 다운로드되어 있는지 확인해야 합니다. 만약 스킬이 존재하지 않을 경우 스킬을 검색하여 다운로드(설치)를 완료하십시오.
- 위 환경 점검 및 스킬 설치가 모두 완료된 후에만 아래 가이드라인의 원칙에 따라 프로젝트 코드 작업을 진행합니다.

## 2. 사전 아이디어 추론 및 사용자와 의도 정립 (Pre-edit Idea Alignment)
어떤 기능을 새로 추가하거나 기존 코드를 수정하기 전, AI 에이전트는 **반드시 사용자에게 어떻게 구현할 것인지 아이디어를 먼저 제시하고 추론**해야 합니다. 사용자가 구상하는 방향과 AI가 제안하는 기술적 해결책, 접근법이 일치하는지 명확히 정립하고 사용자의 동의(Confirm)를 받은 후에만 실제 코드 수정을 진행하십시오. 임의로 판단하여 코드를 짜거나 대규모 수정을 즉각 강행하는 것을 엄격히 금지합니다.

## 3. 시행착오 과정 중 백업 금지 및 GitHub을 통한 버전 관리 (No Manual Backups During Trial & Error)
- **로컬 수동 백업(`_backup.py`) 절대 금지**: 오류를 고치고 디버깅하는 '시행착오(Trial & Error)' 과정 중에는 수동으로 `_backup.py`와 같은 백업 파일을 생성하거나 덮어쓰지 마십시오. 이는 인코딩 충돌로 인한 파일 손상 시 복구를 불가능하게 만들고 작업 디렉토리를 오염시킵니다.
- **백업은 GitHub에 푸시(Push)할 때만 이어서 진행**: 모든 백업과 버전 관리는 오직 **Git**을 통해서만 이루어져야 합니다. 코드가 완전히 정상적으로 작동하고 사용자의 최종 승인(Confirm)이 떨어졌을 때만 `git commit` 및 `git push`를 통해 코드를 백업(저장)하십시오.

## 4. 인코딩 및 파일 수정 주의사항 (Strict Encoding Rules for Korean Characters)
- **PowerShell(Get-Content / Set-Content) 사용 절대 금지**: 한글(UTF-8) 문자가 포함된 소스 코드를 수정할 때, PowerShell 명령어를 사용하여 파일의 내용을 읽고 쓰지 마십시오. Windows PowerShell은 기본 인코딩(CP949) 문제로 인해 UTF-8 한글 데이터를 영구적으로 파괴(Mojibake/글자 깨짐)할 수 있습니다.
- **파일 수정은 반드시 정규 표현식 도구(replace_file_content)나 명시적인 Python 스크립트로 수행**: 파일 내용을 변경할 때는 반드시 시스템에 내장된 파일 수정 도구를 사용하거나, Python 스크립트 작성 시 `open(..., encoding='utf-8')`을 명시하여 안전하게 수정하십시오.

## 5. 파이썬 코드 주입 시 들여쓰기 엄수 (Strict Indentation for Code Injection)
- **메서드 중간 삽입 지양**: 새로운 UI 코드나 메서드를 클래스 내부에 주입할 때, 기존 메서드(`__init__` 등)의 중간에 코드를 끼워 넣지 마십시오. 이는 파이썬의 들여쓰기(Indentation) 규칙을 훼손하여 하위 코드가 모조리 무시되거나 삼켜지는 치명적인 버그(UI 사라짐 등)를 유발합니다.
- **클래스 최하단에 새 메서드 추가**: 새로운 기능을 위한 메서드는 항상 클래스의 가장 마지막 줄(최하단)에 올바른 들여쓰기(예: 4칸)를 맞추어 추가해야 합니다.

## 6. GitHub 푸시(Push)에 대한 엄격한 기준 (Strict GitHub Push Criteria)
- **AI 자체 테스트 결과에 의존한 푸시 절대 금지**: AI가 스스로 디버깅이나 스크립트 실행을 통해 "성공했다"고 판단하더라도 절대 푸시해서는 안 됩니다. AI의 자체 테스트 성공은 푸시의 조건이 될 수 없습니다.
- **푸시 가능 시점**: 오직 **사용자가 직접 로컬에서 프로그램을 켜서 테스트해 보고 "이 기능은 이 정도면 됐다", "완벽하게 작동한다"라고 명시적으로 승인(Confirm)** 했을 때만 커밋(Commit) 및 푸시(Push)를 수행합니다.

## 7. 프로젝트 진행 상황 지속 업데이트 (Continuous Progress Update)
모든 에이전트는 사용자의 요청을 성공적으로 수행하여 특정 기능 구현이나 버그 수정이 완료될 때마다 반드시 **`docs/project_status.txt`** 파일을 열어서 다음 항목들을 최신 상태로 유지해야 합니다.
- **진행된 부분(완료된 작업)**: 방금 해결한 버그나 새로 추가된 기능을 명확히 기록.
- **현재 진행 상황**: 전체 프로젝트 관점에서의 현 위치 요약.
- **진행해야 할 부분(To-Do)**: 아직 구현하지 않은 남은 과제나 다음 목표를 갱신.

## 8. 작업 후 잉여 파일 정리 (Clean Up Residual Files)
특정 기능 구현이나 오류 수정을 위해 임시로 생성한 테스트 스크립트(`test_*.py`), 디버깅 파일(`debug_*.txt`), 수정 스크립트(`fix_*.py`) 등은 작업이 성공적으로 마무리된 후 **반드시 삭제하여 작업 디렉토리를 깨끗하게 유지**해야 합니다.

## 9. 폴더 내 생성 파일 관리 및 경로 제한 (Strict File Generation Scope)
새로운 스크립트, 데이터 파일, 또는 출력 파일의 생성과 관리는 반드시 `AcousticStudio` 디렉토리(및 그 하위 폴더) 내에서만 생성하고 관리해야 합니다. 바탕화면이나 외부 폴더에 파일을 생성하여 작업 환경을 지저분하게 만들지 마십시오. 특히 디버깅용 텍스트 파일은 `scratch`와 같은 별도 하위 폴더를 활용하십시오.

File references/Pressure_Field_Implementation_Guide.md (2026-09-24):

# 음압 분포(Acoustic Pressure Field) 시각화 통합 가이드

기존에 성공적으로 구현하신 **위상(Phase) 시각화**에 이어, 실제 공간에 형성되는 **음압(Pressure) 분포**를 AcousticStudio (PyVista + PySide6) 환경에 통합하기 위한 가이드입니다.

## 1. 이론적 배경 (레일리 적분 - 점음원 근사)

초음파 위상 배열(Phased Array)의 음압을 실시간 3D 환경에서 계산하기 위해서는 복잡한 FEM/BEM 연산 대신 **레일리 적분(Rayleigh integral)의 점음원(Point-source) 근사법**을 사용하는 것이 가장 효율적입니다.

특정 공간 좌표 $(x, y, z)$에서의 복소 음압 $P(x,y,z)$는 배열 내 모든 트랜스듀서 $n$의 기여도를 합산하여 구합니다.

$$ P(x, y, z) = \sum_{n=1}^{N} P_0 \frac{e^{j (k r_n + \phi_n)}}{r_n} $$

*   $P_0$: 기준 진폭 (트랜스듀서 1개의 출력 강도)
*   $k$: 파수 (Wave number, $k = 2\pi f / c$)
*   $r_n$: $n$번째 트랜스듀서와 공간 좌표 $(x, y, z)$ 사이의 거리
*   $\phi_n$: $n$번째 트랜스듀서에 인가된 위상(Phase) 지연값

최종적으로 우리가 시각화할 실제 **음압 크기(Amplitude)**는 복소 음압의 절댓값 $|P(x,y,z)|$ 입니다.

## 2. 통합 구현 파일 (파이썬 코드)

동봉된 `pressure_field_example.py` 파일은 위 수식을 `numpy` 행렬 연산으로 최적화하여 구현한 예제 코드입니다. 이를 AcousticStudio 코드에 통합할 때 다음 과정을 거칩니다.

### A. PyVista 볼륨/단면 매쉬 생성
PyVista의 3D 공간을 모두 연산하면 연산량이 너무 많아 실시간(Interactive) 조작이 끊길 수 있습니다. 따라서 다음과 같은 접근을 추천합니다.
1.  **단면 시각화 (Slice Visualization):** 특정 평면(예: xy평면 또는 xz평면)에 대해서만 `StructuredGrid`를 생성하여 음압을 계산합니다.
2.  **등위면 시각화 (Isosurface):** 3D 볼륨(Volume) 격자를 성기게 생성하여 음압을 계산한 뒤, `grid.contour()`를 활용하여 음압이 특정 임계값(예: 초음파 트랩을 형성하는 노드 근처)을 넘는 영역만 3D 덩어리로 시각화합니다.

### B. 실시간 연산 최적화 (GPU 또는 Numba)
마우스 기즈모로 트랜스듀서를 드래그할 때마다 음압을 계산하려면 `numpy` 연산 속도가 중요합니다. 만약 해상도를 높여서 버벅임이 발생한다면:
*   `numba`의 `@jit(nopython=True, parallel=True)` 데코레이터를 사용하여 다중 코어 연산을 활성화하세요.
*   공간 내 트랜스듀서와 그리드 간의 거리를 사전에 계산해두고, 위상(Phase, $\phi_n$)이 바뀔 때만 `exp()` 부분만 다시 계산하도록 최적화할 수 있습니다.

## 3. 참고 문헌 및 기존 논문 활용
현재 폴더에 이미 존재하거나 참고할 만한 논문들입니다:
1.  **"Holographic acoustic elements for manipulation of levitated objects" (기존 폴더 존재)**: 복소 음압장과 위상 변조를 통한 트랩핑(Trapping) 노드 형성의 수학적 모델이 자세히 나와 있습니다.
2.  **"Ultraino: An Open Phased-Array System..." (기존 폴더 존재)**: 오픈소스 기반 위상 배열의 음압 계산(C++ 기반) 및 하드웨어 전송에 대한 아키텍처를 참고할 수 있습니다.
3.  **오픈소스 라이브러리 `levitate` (Python)**: 만약 더 복잡한 초점 제어나 힘(Force) 계산이 필요하다면 GitHub의 `AppliedAcousticsChalmers/levitate` 라이브러리를 추가로 설치(pip install levitate)하여 엔진으로 활용할 수 있습니다.

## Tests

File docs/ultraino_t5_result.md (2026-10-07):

# T5 통신·캘리브레이션 소프트웨어 구현 및 검증 결과

2026-10-07. 사용자 요청에 따라 완료한 T4를 [1d3d83f](https://github.com/ekkukdl/AcousticStudio/commit/1d3d83faa289d0cc9d619fc37097d954442e5052)로 main에 push하고 원격 HEAD 일치를 확인한 뒤 T5를 구현했다. **Creo R2 8면·8기판·기판당 32개·총 256채널**을 유지한다. T5 소프트웨어 및 fake-serial 검증은 완료했으며 실제 컨트롤러/펌웨어/배선·출력 OFF·파형 측정은 남아 있다. 다음 소프트웨어 단계는 [T6 조작·이송](ultraino_migration_plan.md)이다. T5 변경은 현재 로컬 작업 상태다.

## 앱에서 확인하는 순서

1. 기존 Creo 터널 프리셋과 제어점을 추가한다. 상단 `보드` 메뉴에서 사용할 256채널 프로파일을 선택한다. 실제 펌웨어가 미확정이면 COM을 연결하지 않고 프레임/파일 검증부터 한다. **8 PCB 수로 FPGA 주소나 프로파일 분할을 결정하지 않는다.**
2. `보드 → 채널 보정·맵 및 OFF 프레임…`을 연다. 보정 설정 변경은 연결을 해제한 상태에서 한다. 소프트웨어 채널별 명령 위상 오프셋(rad), 고정 상대 음원 이득, 활성 여부를 입력한다. 기본 위상 보정은 0, 이득은 1, 활성은 켜짐이다.
3. `Creo 후보 맵 읽기`로 기존 후보 맵을 불러온다. 마지막 열은 **map[물리 행]=소프트웨어 채널**이며 왼쪽 위상/이득/활성 열은 소프트웨어 행이다. 중복/누락/실수/불리언 맵은 거절한다. 수동 편집하면 맵 출처 상태가 수동 미검증으로 바뀐다. `항등 맵`으로 초기화할 수 있으나 실제 배선의 항등 여부를 확인한 것으로 표시하지 않는다.
4. 보정 ID와 설명을 입력하고 `보정 적용`을 누른다. 실제 측정 자료를 입력할 때만 실측 출처를 선택하고 측정 조건·펌웨어 ID·배선 버전을 기록한다. 이 표시는 입력자의 출처 기록이며 프로그램이 실측을 수행한 증거가 아니다.
5. 공통 음향 모델로 위상을 다시 계산한다. 보정 이득·비활성 상태는 Focus/Twin/Vortex/Kinoforms, 단면, T3 고정 위상 분석, 궤적 계산에 동일하게 반영한다. `보정 JSON 저장/읽기`와 프로젝트 저장·Undo/Redo를 지원한다. 배열·채널 순서·프로파일이 다른 보정은 거절하며, 보정 창에서 새로 작성하거나 `보정 제거`로 초기화한다.
6. COM 없는 검증은 `1채널 프레임 저장` 또는 `전체 OFF 프레임 저장`을 사용한다. 한 채널은 해당 SW 채널의 보정·맵을 반영하고 나머지는 OFF다. Legacy는 OFF 근거가 없어 이 동작을 거절한다. 일반 궤적 내보내기도 비활성 채널이 있는데 OFF를 지원하지 않으면 파일 생성 전에 거절한다.
7. 실제 컨트롤러·펌웨어·배선이 확인된 하드웨어 작업에서는 `보드 → 단일 채널 테스트 전송…` 및 `전체 채널 OFF 전송`을 사용할 수 있다. 비활성 보정 채널의 단독 테스트는 먼저 활성화해야 한다. 이번 검증에서는 fake serial만 연결했으며 실제 COM 송신을 실행하지 않았다.

[보정 창 캡처](../scratch/ultraino_migration/t5_calibration_dialog.png), [검증용 프로젝트](../scratch/ultraino_migration/t5_example_project.json), [예시 보정 JSON](../scratch/ultraino_migration/t5_example_calibration.json), [예시 258-byte 프레임](../scratch/ultraino_migration/t5_example_frame.bin)을 남겼다. 프로젝트는 예시 보정과 동일한 배열 인스턴스 ID를 포함하므로 함께 재현할 수 있다. 보정 JSON만 새로 생성한 다른 배열에 불러오면 배열 서명이 달라 거절한다. 이 예시는 SW0 위상 −0.3rad, SW1 상대 이득 0.7, SW2 비활성의 **미실측 데이터**다. 실제 보드용 보정은 현재 배열에서 별도로 작성한다.

## 공통 데이터 및 송신 계약

| 데이터 | 계약 |
| --- | --- |
| `Calibration` | 불변 schema1, 보정 ID·UTC 시간·SW 순서 오프셋/이득/활성 상태 |
| 위상 보정 | `command_phase = ideal_phase + offset_rad`. 관측 위상 오차가 +이면 상쇄 오프셋은 − |
| 상대 이득 | 기존 nominal 음원 가중치 × `source_gains`; 비활성이면 0. 가변 구동 진폭 명령은 아님 |
| 계산 위상 | 보정 후 이상적인 방사 위상. 시뮬레이션에 명령 오프셋을 다시 더하지 않음 |
| 채널 맵 | `map[physical_frame_channel]=software_channel`; 위상과 활성 상태 모두 같은 방향으로 변환 |
| 활성 마스크 | 호출자의 음원 이득>0 마스크와 보정 활성 상태의 AND; 이득 0도 OFF |
| 출처 | 수동/실측 보정 상태, 맵 상태·출처·SHA256, 조건·펌웨어·배선·수정 이력 |
| 음압 | `gain_units=relative_to_nominal`, `pressure_calibrated=false`. 절대 Pa 보정 표시는 거절 |

실시간과 궤적 파일은 같은 경로를 사용한다.

```text
이상적인 SW 위상
  → SW 명령 위상 오프셋 적용 1회
  → 위상 및 활성 상태를 물리 순서로 매핑
  → 선택 프로파일의 반올림/2π wrapping/OFF
  → 선택 프로파일의 전체 프레임·commit 인코딩
```

`hardware.py`의 `prepare_phase_steps`, `build_phase_frame`, `send_phases`와 `trajectory_export.py`가 이 계약을 공유한다. binary는 송신 프레임 그대로 이어 붙인다. CSV/C 헤더의 위상 열은 이미 보정·맵이 적용된 물리 채널 순서이며 보정 ID도 기록한다. C 헤더는 지원 프로파일의 32=OFF를 명시한다. legacy FA 파일 컨테이너는 종전 형식으로 보존한다. binary에는 시간·보정 메타데이터가 없으므로 프로젝트/보정 JSON과 함께 관리한다. 물리 순서의 내보낸 값을 SW 입력 API에 다시 넣으면 이중 보정·매핑이 되므로 재인코딩하지 않는다.

배열 서명은 순서대로 CAD 인스턴스 ID·채널·기하 ID·원본 입력 해시·기준 방사면 행렬을 포함한다. CAD 전체 강체 이동/회전은 보정을 유지하고 채널 순서·기준 형상·새 배열 인스턴스는 서명을 바꾼다. Legacy는 저장된 송신기 행렬에 묶이므로 배열 좌표를 변경하면 새 보정을 작성한다. 목표점 이동은 서명에 영향을 주지 않는다.

`hardware_settings`와 `calibration`을 프로젝트·Undo/Redo에 저장하며 보정 JSON과 하드웨어의 맵/오프셋/활성 설정이 일치하는지 먼저 검사한다. 손상된 새 필드는 장면 변경 전에 거절한다. 이전 프로젝트의 필드 누락은 무보정 상태와 기존 `board_profile` 또는 Legacy 기본값으로 복원한다. 새 프로젝트는 보정을 초기화하고 연결 상태에서 다른 설정을 복원하려 하면 연결 해제를 요구한다. 원본 CAD 좌표·기판 뱅크 구조를 재생성하지 않는다.

## 프로파일과 반올림·OFF 근거

| 프로파일 | framing | OFF | 활성 위상 반올림 |
| --- | --- | --- | --- |
| Legacy Phase32 | FE + phase bytes + FD, 가변 채널 | 미지원 | 기존 ties-to-even 유지 |
| Ultraino SimpleFPGA 256 | FE + 256 bytes + FD | 32 | nearest, ties toward +∞ |
| SonicSurface direct 256 | FE + 256 bytes + FD | 32 | 클라이언트 정책 nearest, ties toward +∞ |
| SonicSurface board tags | FE C0 + 128 bytes + C1 + 128 bytes + FD | 32 | 같은 클라이언트 정책 |
| SonicSurface ESP32 command | `phases=` + 256 정수와 마지막 쉼표 + LF | 32 | 같은 클라이언트 정책 |

원본 [SimpleFPGA.java](../../simulations/Ultraino/AcousticFieldSim/src/acousticfield3d/protocols/SimpleFPGA.java)는 PHASE_OFF=getDivs()=32이며 [Transducer.java](../../simulations/Ultraino/AcousticFieldSim/src/acousticfield3d/simulation/Transducer.java)의 `calcDiscPhase`는 Java Math.round를 사용한다. Python 기본 반올림과 반 스텝이 달라 Ultraino 프로파일에서 명시적으로 분리했다. Java의 float32 전체 연산과 Python float64의 경계 근처 비트 단위 일치를 주장하지 않으며 수학적 반올림 규칙·정확한 반 스텝·인접값을 테스트했다.

[CommandSenderESP32.ino](<../../simulations/SonicSurface/Firmware/ESP32 controller/CommandSenderESP32/CommandSenderESP32.ino>)와 [TestHoloConnection4.ino](<../../simulations/SonicSurface/Firmware/ESP32 haptic controller/TestHoloConnection4/TestHoloConnection4.ino>)에서 32=OFF, 기존 프레임/commit을 확인했다. ESP32 `phases=`는 정수 값을 받아 전달하므로 반올림은 AcousticStudio의 클라이언트 정책이다. 원본 펌웨어가 위상을 추가로 양자화한다고 가정하지 않는다.

활성 위상은 modulo 2π 후 반올림하고 modulo32로 wrapping한다. 31.5스텝이나 2π 근처가 활성 위상0으로 돌아가며 OFF32가 되지 않는다. OFF는 별도의 활성 마스크에서만 부여한다. 지원되지 않은 OFF·부분 채널 수·NaN/Inf·잘못된 맵은 송신 전에 거절한다.

**8기판≠8 FPGA 주소, 16뱅크≠16 체인 보드**다. 후보 맵은 [channel_map.csv](../구상도/outputs/panel_8faces_32ch_R1/channel_map.csv)의 `fpga_physical_channel`과 전 채널 일치하지만 실제 DATA/header/SHIFT/LATCH/ARM 할당은 확인하지 않았다. 기존 128채널 태그 분할과 원본 Ultraino의 256채널 단위 [ChainedFPGA.java](../../simulations/Ultraino/AcousticFieldSim/src/acousticfield3d/protocols/ChainedFPGA.java)를 32채널 PCB 수만으로 수정하지 않았다. 자동 수신기 기반 채널 할당은 장비가 준비된 후속 하드웨어 작업이다.

## 쓰기 실패와 수명 처리

`serial.Serial`에 `write_timeout=0.1s`를 설정한다. `send_packet`은 전체 프레임의 단일 write가 완료되면 True, 연결 없음·부분 쓰기·timeout·예외면 False다. 부분 프레임의 나머지를 재시도하거나 재연결 시 자동 재생하지 않는다. 실패 신호 후 포트를 닫으며 실제 UI의 실시간 전송 체크도 해제한다.

GUI 스레드에서 무한 대기할 수 있는 `serial.flush()`는 호출하지 않는다. `send_phases` 반환 frame은 결정론적 비교용이며 실패 시에도 생성된 frame을 반환할 수 있다. 실제 전달 성공 여부는 `send_packet`의 반환값/실패 신호로 확인한다. 로컬 write 성공은 보드 ACK·wire 전달 완료·출력 OFF의 증거가 아니다. 연결 해제만으로 실물 출력이 꺼졌다고 표시하지 않는다.

현재 write 호출은 기존 GUI 경로에서 최대 설정 timeout까지 대기할 수 있다. 일반 송신 큐·계산/송신/렌더링 주기 분리·프레임 폐기 정책은 T6에서 확장한다. 실제 드라이버 지연이나 지속 갱신률을 이 fake-serial 검증으로 보장하지 않는다.

## 구현 파일과 실행한 검증

| 파일 | 역할 |
| --- | --- |
| [calibration.py](../src/acousticstudio/calibration.py) | 검증된 불변 보정 데이터·출처·이력·배열 서명·후보 맵 로딩 |
| [calibration_ui.py](../src/acousticstudio/calibration_ui.py) | 기존 창에서 수동 편집·읽기/저장·OFF 프레임 파일 생성 |
| [hardware.py](../src/acousticstudio/hardware.py) | 기존 컨트롤러 확장, 마스크·프로파일 양자화·OFF·bounded write |
| [trajectory_export.py](../src/acousticstudio/trajectory_export.py) | 동일 프레임/Phase32+OFF·보정 ID 내보내기 |
| [app.py](../src/acousticstudio/app.py), [geometry_scene.py](../src/acousticstudio/geometry_scene.py), [geometry.py](../src/acousticstudio/geometry.py) | 보드 메뉴·공통 이득 입력·상태 저장/복원·활성 상태 검증 |
| [test_calibration.py](../tests/test_calibration.py), [test_calibration_ui.py](../tests/test_calibration_ui.py) | 순서/보정/반올림/OFF/실패·실제 Qt 편집·전체 메인 연결 회귀 |

전체 pytest는 **208 passed, 3 skipped, 6 warnings, 20.69s**다. [JUnit](../scratch/ultraino_migration/t5_pytest.xml)에 211개 사례를 기록했다. skip은 기존 CUDA 없는 PyTorch 사례이며 warning은 기존 Taichi locale 1건과 기존 matplotlib get_cmap을 새 GUI 회귀가 호출한 5건이다. 테스트 중 발견한 기존 Legacy export fixture의 이득0은 이제 OFF 미지원으로 거절해야 하므로 일반 export 기준은 양의 이득으로 바꾸고 별도의 Legacy 이득0 거절 회귀를 추가했다.

새 검증은 반 스텝/음수/2π 경계, 위상0≠OFF, 맵 순열과 보정 부호·활성 매핑, 전체 OFF·한 채널, 같은 송신/내보내기 바이트, 프로파일/출처/절대 음압 오기입 거절, 이력/프로젝트/Undo/Redo, 배열 서명과 pose 독립성, 손상된 설정의 원자적 거절, 부분 write/timeout/연결 실패/health 실패·재연결 자동 재생 없음 등을 확인한다. 실제 GUI에서도 후보 맵 읽기·수동 수정·중복 맵 실패 후 초기화·JSON·OFF 파일을 실행했다.

[재현 도구](../scratch/ultraino_migration/verify_t5_pipeline.py)는 채널 CSV와 후보 맵 전 채널 비교 및 독립 코드의 4프로파일 × 일반/1채널/전체 OFF **12건**을 검증했다. 각 frame은 fake 송신·binary와 같고 CSV/C 헤더 값·보정 ID도 확인했다. 실제 메인 창에서 보정 적용 → T4 Kinoforms → 같은 이득의 T3 고정 위상 분석 → fake 송신/내보내기 → 보정 제거/프로젝트 복원까지 확인했다. [검증 JSON](../scratch/ultraino_migration/t5_pipeline_result.json)에 수정 소스·원본 프로토콜/펌웨어·CAD/채널 파일의 SHA256을 남겼다.

T3 예시 Focus 후보는 수렴했으나 전체 K의 음의 고유값으로 `non_restoring`이었다. 상대 이득/위상 보정 데이터를 저장했다고 절대 음압 보정이나 부양 성공으로 바꾸지 않았으며 `unavailable_uncalibrated_pressure`를 유지했다. 창 캡처는 확인했지만 3D 뷰포트 캡처·실제 파형·부양·k-Wave는 검증하지 않았다.

기존 Anaconda Python3.13.9/NumPy/Qt/pyserial/Numba/T2 DLL과 기존 CAD 입력을 재사용했다. 새 환경·패키지 설치·DLL 재빌드·CAD 재생성·backup 갱신은 없다. 관련 없는 Creo `std.out`은 보존했다.

저장소 루트에서 실행한다. 아래 도구는 실제 COM 생성자를 차단하고 fake serial을 사용하며 예시 프로젝트·보정·frame·캡처·검증 기록을 갱신한다.

```powershell
$env:PYTHONPATH='src'
$env:QT_QPA_PLATFORM='offscreen'
$env:PYTHONIOENCODING='utf-8'
& 'C:/Users/line0/anaconda3/python.exe' -m pytest -q --junitxml=scratch/ultraino_migration/t5_pytest.xml
& 'C:/Users/line0/anaconda3/python.exe' scratch/ultraino_migration/verify_t5_pipeline.py
& 'C:/Users/line0/anaconda3/python.exe' scratch/ultraino_migration/verify_t5_static.py
```

[정적 도구](../scratch/ultraino_migration/verify_t5_static.py)와 [기록](../scratch/ultraino_migration/t5_static_result.json)은 Python 51개 AST·문서 15개 UTF-8/로컬 링크 193개, T2 native/T4 공통 음장/T5 수정 입력·원본 프로토콜 해시, 프로젝트/보정/프레임 계약, JUnit과 `git diff --check`를 확인했다.

## 다음 에이전트의 T6 시작 기준

1. AGENTS.md, 계획, T4/T5 결과를 읽고 `git status --short`를 확인한다. 현재 T5 변경은 아직 커밋하지 않았다. T6 소프트웨어 선행 경로는 준비되었고 실제 펌웨어·배선·OFF 검증은 별도로 남아 있다.
2. `source_inputs(window)`의 보정 이득/활성과 T2 `field_kwargs`의 CAD 법선/개구, T4 worker/controller의 최신 요청/취소 구조를 재사용한다. 위상·시리얼·저장 계층을 중복 작성하지 않는다.
3. 기존 이벤트 필터/VTK picking을 확장해 단면 클릭·드래그의 세계 좌표, 선택/전체 제어점 XYZ 이동을 연결한다. 터널 이송 축은 Z다. T4의 phase-only 혼합 목표를 유지하고 매 waypoint 한 목표인 기존 궤적과 동시 다중 목표 이송을 구분한다.
4. GUI/VTK는 메인 스레드에서, 숫자 계산은 불변 스냅샷 worker에서 처리한다. 계산·송신·음장 그래프 주기를 분리하고 오래된 요청/프레임을 버리며 드래그 해제의 최종 위치를 적용한다. T5 write timeout과 실패 신호를 재사용하고 재연결 후 오래된 프레임을 자동 송신하지 않는다.
5. picking 좌표, 이동·정지·취소·창 닫기, 최종 위치/요청 순서, 렌더링·송신 중복과 bounded 큐를 fake-serial/Qt로 검증한다. 기존 궤적의 동기 계산은 worker로 옮길 때 오류·진단 실패 표시와 export 일치를 유지한다. stiffness norm/균일도를 부양 성공률로 사용하지 않는다.
6. 통신선 전송 시간과 실제 계산/드라이버 지연을 분리한다. 230400baud 8N1의 258byte 프레임은 선로만 약11.2ms이며 1ms 송신을 약속하지 않는다. 실제 컨트롤러/펌웨어·DATA 배선·채널 파형/OFF·유효 개구·입자·음압 보정이 확인된 사용자 요청 하드웨어 단계에서 지속 갱신률 및 T7 부양·Z 이송·정지 유지 실험을 기록한다.

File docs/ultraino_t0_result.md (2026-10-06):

# T0 구현 및 검증 기록

2026-10-07. 기준: Creo R2의 8면·8기판·32 TX/기판, 총 256채널. 이 단계는 기존 계산·송신 경로를 바로잡는다. CAD 프리셋은 T1에서 연결한다.

## 다음 에이전트가 재사용할 진입점

- [PhaseEngine](../src/acousticstudio/phase_engine.py): `calculate_phases(centers, active_points, amplitudes, algorithm, mode_idx, ...)`는 mm 좌표와 소프트웨어 채널 순서의 rad 위상 `(N,)`을 사용한다. `calculate_trajectory_phases`는 각 경유점을 단일 목표점으로 계산해 `(steps,N)`을 반환한다. 정지 목표점과 이동 목표점의 동시 재생은 T6 범위다.
- `optimize_trajectory_physical`은 같은 위상 진입점 및 실제 설정 진폭을 사용한다. 지연 단위는 ms다. 실패 시 점수·강도·스티프니스는 None, `valid=False`다. `trajectory_diagnosis_is_valid`는 이전 저장 파일의 Fallback 점수도 거른다.
- [HardwareController](../src/acousticstudio/hardware.py): `set_phase_offsets`는 소프트웨어 채널 순서의 **가산 rad 보정**을 설정한다. `set_channel_map`은 `map[physical]=software`를 설정한다. `prepare_phases`에서 입력 채널 수 검증 → 보정 → 맵을 한 번씩 적용한다. `prepare_phase_steps`와 `build_phase_frame`은 파일/실시간 공통 경로다. 보드 프로파일 변경은 맵과 보정을 초기화한다. 보정 API는 메모리에서만 동작하며 측정·UI·저장 기능이 아니다.
- [파일 출력](../src/acousticstudio/trajectory_export.py): `save_trajectory_export`는 원래 소프트웨어 순서의 위상을 받는다. 헤더/CSV에는 보정 완료 물리 채널 순서를 명시한다. 일반 `.bin`은 선택 프로파일 프레임 연결이며 타이밍/메타데이터가 포함되지 않는다. `legacy` 선택과 `.legacy.bin`은 이전 `0xFA + Phase32 + 0xFD` 파일 컨테이너다. CSV에는 `Board_Profile`과 `PhysicalN_Phase32` 열이 추가되었다. 기존 외부 CSV 소비자는 이 변경에 맞춰야 한다.
- [의존성 카탈로그](../src/acousticstudio/dependencies.py): `main.py`, `installer_ui.py`가 같은 `PACKAGE_INFO`를 사용한다. 필수 9개는 requirements.txt와 일치한다. [확인한 버전](../requirements-tested.txt)은 기존 환경의 핵심 패키지 스냅샷이며 신규 환경 설치를 검증한 잠금 파일은 아니다.

## 실제 실행한 검증

사용 인터프리터: `C:/Users/line0/anaconda3/python.exe`, Python 3.13.9. pytest 8.4.2. 새 설치 없음.

AcousticStudio 루트에서:

```powershell
& 'C:/Users/line0/anaconda3/python.exe' -c "import sys; sys.path.insert(0,'src'); import pytest; raise SystemExit(pytest.main(['tests','-q']))"
```

결과: **58 passed, 1 warning, 4.00s**. 기존 7개 테스트가 포함된다. [계산/송신/파일 회귀 테스트](../tests/test_trajectory_pipeline.py)와 [Qt 핸들러 회귀 테스트](../tests/test_trajectory_ui.py)를 추가했다.

- 5개 송신기/2개 목표점: Focus/Twin/Vortex의 NumPy 기준 계산 및 실제 C++ DLL 위상이 일치했다. DLL 부재 시 다중 목표점과 궤적 경유점 계산이 지원되었다.
- 역순 C++ 인자, 잘못된 채널 수/진폭, 비정상 계산 결과를 검출했다. 물리 라이브러리 부재/예외/영 강도/NaN/크기 오버플로/잘못된 벡터/빈 입력에는 성공 점수가 생성되지 않았다.
- 비순차 채널 맵과 서로 다른 보정을 적용한 5개 프로파일에서 fake-serial 송신과 `.bin` 바이트가 일치했다. 헤더/CSV/legacy의 위상 값도 같은 순서였다. 실제 포트를 열지 않았다.
- 실제 설치된 Levitate로 두 경유점의 유한 스티프니스가 계산되었다. 물리 안정성의 정확성을 확인하는 시험은 아니다.
- offscreen Qt 레이블, 궤적 생성/내보내기 핸들러, 라이브러리 관리자의 누락 필수 항목을 확인했다. 전체 VTK 앱 창·3D 렌더링은 실행하지 않았다.
- 필수 설치 검사 실행, 두 UI의 동일 카탈로그 사용, requirements.txt 집합 일치, Python 파일 18개 AST 문법 검사 통과. `git diff --check` 통과.

Taichi의 기존 import 경로가 GPU 런타임을 초기화하고 `locale.getdefaultlocale` 사용 중단 경고를 한 번 출력했다. GPU 계산 커널, k-Wave solver, 실제 보드 송신·부양 및 CAD 재생성은 수행하지 않았다. `backup/`과 commit/push도 갱신하지 않았다.

## 남은 경계 및 이어서 할 작업

현재 물리 진단은 기존 ±Z 법선 추정과 5mm 유효 개구, 스티프니스 크기 기반 상대 점수를 사용한다. 이 모델은 내향 8면 터널의 물리 검증을 대신하지 않는다. T2에서 CAD 법선·음향 개구를 연결하고 T3에서 힘 부호·복원 방향·입자 물성으로 검증한다. T5에는 측정 보정/영구 저장/OFF/펌웨어별 반 스텝 경계가 남아 있다.

다음은 [계획의 T1](ultraino_migration_plan.md): 기존 `array_positions_256.json` 로더와 프리셋을 추가하고 위치·법선·ID·채널 순서를 렌더링/저장·복원/Undo에서 유지한다. 일반 Tube 계산식으로 좌표를 다시 생성하지 않는다.

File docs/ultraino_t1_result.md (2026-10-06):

# T1 Creo 터널 배열 연결 및 검증 기록

2026-10-07. T0에 이어 **8면·8기판·32송신기/기판, 총 256채널**의 Creo R2 프리셋을 구현했다. 다음 작업은 [계획의 T2](ultraino_migration_plan.md)다.

## 사용 방법과 표시 범위

`구성 → 배열 형태 → Creo 8면 터널 · 8기판 × 32채널 → 배열 3D 렌더링 생성`을 사용한다. 위치와 회전 입력으로 전체 조립체를 배치한다. 일반 모델/Grid/Spacing 입력을 숨기고 CAD 고정 치수를 안내한다. 기존 일반 Tube와 분리된 추가 프리셋이며 이미 있는 배열에 더해 생성한다. 보드 프로파일은 실제 펌웨어에 맞게 별도로 선택한다.

송신기는 CAD 외형 16mm, 높이 12.5mm의 원통이다. PCB 8개는 원본 84×224×1.6mm 치수·행렬, 프레임 링 2개는 R2의 내외측 아포템·높이·행렬로 표시한다. 구조물은 반투명 간략 표시이며 슬롯·나사홀·전자부품을 구현한 제조용 솔리드는 아니다. 새 CAD 생성기나 STEP 변환 의존성을 추가하지 않았다.

[독립 VTK로 확인한 3D 미리보기](../scratch/ultraino_migration/creo_tunnel_preview.png).

## 다른 에이전트가 이어서 사용할 구조

| 위치 | 책임과 계약 |
| --- | --- |
| [geometry.py](../src/acousticstudio/geometry.py) | `load_creo_tunnel()`은 패키지/저장소 위치 기준으로 기존 두 JSON을 읽는다. 작업 CWD와 사용자 이름을 하드코딩하지 않는다. `validate_geometry()`는 저장 스냅샷의 좌표·법선·회전·채널 순서·구조물 관계를 확인한다. `transform_geometry()`는 전체 방사면과 법선·구조물을 함께 변환한다. |
| [geometry_scene.py](../src/acousticstudio/geometry_scene.py) | GUI 스레드의 VTK 어댑터다. `create_geometry_actors`는 256개 송신기 및 10개 구조물 actor를 만든다. 원점은 방사면, 로컬 +Z가 방사 방향, 몸체는 로컬 -Z에 있다. `transducer_inputs()`는 CAD 모델 방사면 좌표·진폭을 읽고 레거시에는 기존 actor 좌표 어댑터를 사용한다. |
| [app.py](../src/acousticstudio/app.py) | `geometry_arrays`를 모델 원본으로 보존한다. CAD actor의 `_geometry_element`는 해당 모델의 채널 레코드를 참조한다. CAD 선택은 전체 배열로 확장하고 모델/방향을 바꾸는 개별 속성 편집은 막는다. UI 변환 후 `_sync_cad_geometry()`가 모델 및 구조물의 전체 pose를 갱신한다. |
| `get_state` / `set_state` | JSON과 Undo 스냅샷 양쪽에 `geometry_arrays`를 깊은 복사로 저장한다. 송신기 목록은 `geometry_instance`와 `geometry_channel`로 모델을 참조한다. CAD 구조물은 별도 음향 채널로 넣지 않는다. 저장된 스냅샷은 원본 CAD 파일 없이 복원할 수 있다. 누락·중복·재배열된 CAD 채널과 불일치 행렬은 장면을 지우기 전에 거절한다. |

스키마 버전 1은 `geometry_id`, 고유 `instance_id`, 단위 mm, 원본 좌표계/상태, 두 입력 JSON의 SHA-256, 치수, `world_transform`, `elements`, `supports`를 담는다. 송신기의 ID·channel·face/local_channel/row/column·bank·원본/세계 방사면 좌표·법선·진폭 가중치·활성 상태·주파수와 유효 음향 개구 미확정 값을 보존한다. 주파수 40kHz와 진폭 1은 초기 설정이며 실측 보정값이 아니다. 물리 맵의 후보 값은 원본 그대로 보존하며 송신 맵으로 자동 적용하지 않는다.

CAD의 방사면 위치와 `actor.center`는 **6.25mm** 차이 난다. 현재 PhaseEngine 호출, 음압 단면, 궤적 진단과 파일 출력은 모델 좌표를 사용한다. T2에서는 같은 모델의 법선 및 확정된 음향 개구를 공통 전파 모델에 연결한다. CAD 외경의 반경 8mm를 유효 음향 개구로 자동 가정하지 않는다.

## 검증과 재현

Anaconda Python 3.13.9를 그대로 사용했다. 새 환경·패키지를 생성/설치하지 않았다.

```powershell
# AcousticStudio 루트
& 'C:/Users/line0/anaconda3/python.exe' -c "import sys; sys.path.insert(0,'src'); import pytest; raise SystemExit(pytest.main(['tests','-q']))"
& 'C:/Users/line0/anaconda3/python.exe' 'scratch/ultraino_migration/verify_creo_preset.py'
```

최종 전체 테스트: **76 passed, 1 warning, 6.27s**. T0의 58개와 [T1 회귀 테스트](../tests/test_creo_geometry.py) 18개를 포함한다. 안내 레이아웃 조정 중 CAD/기존 UI의 집중 검사 19개도 통과했다.

- 256개 방사면·법선을 Creo R2의 송신기 및 면 행렬과 직접 비교했다. 원본 JSON 일치, face별 32개, 열 좌표 -29/-11/11/29mm, Z 좌표 -70..70mm/20mm 간격, 해시를 확인했다.
- face0/face2/대향 face4에서 VTK 로컬 방사면과 몸체 중심을 확인했다. PCB bounds와 두 링의 Z 위치를 확인하여 행렬 전치가 한 번 적용되는지 검증했다.
- 이동/회전과 법선·구조물 변환, ID·순서 보존, 저장/불러오기, Undo/Redo, 전체 삭제, 원본 파일 없는 스냅샷 복원, 잘못된 채널 순서 거부를 확인했다. 일반 Tube와 이전 test1.json도 읽었다.
- 실제 `AcousticStudioMain`을 Qt offscreen으로 초기화하고 프리셋 선택·입력 제어·생성·저장/복원을 확인했다. 설정은 임시 파일로 격리했고 리소스 모니터 스레드 시작과 실제 보드 연결을 하지 않았다. [실행 결과 JSON](../scratch/ultraino_migration/creo_preset_smoke_result.json)과 [재현 스크립트](../scratch/ultraino_migration/verify_creo_preset.py)를 남겼다.
- 같은 VTK 어댑터를 독립 offscreen Plotter에서 렌더링하고 PNG를 직접 확인했다. Qt offscreen의 뷰포트 캡처는 `Render window is not current`로 실패했으므로 성공으로 보고하지 않는다. Qt 위젯 캡처는 제어부 검사용이며 왼쪽 뷰포트의 빈 표시를 실제 데스크톱의 정상 3D 렌더링으로 해석하지 않는다.
- 최종 정적 검사: Python 파일 23개 AST, 문서 9개 UTF-8, 로컬 링크 97개와 `git diff --check` 통과.

실제 보드 송신·부양, 정상 데스크톱 Qt에서 마우스 픽킹·3D 조작, CAD 재생성, GPU 계산 커널 및 k-Wave solver는 실행하지 않았다. 기존 import의 Taichi 런타임 초기화/locale 사용 중단 경고는 T0와 같다. `backup/`, commit/push는 갱신하지 않았다.

UI 지연 입력은 T0의 양수 계약에 맞춰 1ms 이상으로 정리했다. 이전 저장 파일의 0 이하 지연은 기존 재생 fallback인 10ms로 읽는다. 이 설정은 실제 보드의 1ms 갱신 가능성을 보장하지 않는다.

## T2 전달 내용

현재 법선은 모델에 올바르게 저장되지만 물리 엔진은 아직 기존 ±Z 법선 추정·5mm 유효 개구와 상대 스티프니스 크기 모델을 사용한다. T2에서 모델 법선을 PhaseEngine의 공통 복소 음장에 전달하고, T3에서 방향별 힘·복원성과 실제 입자 조건을 검증해야 한다. 현재 장면 및 상대 점수를 실제 터널의 부양 검증으로 취급하지 않는다.

다음 에이전트는 AGENTS.md, 이 문서, ultraino_migration_plan.md의 T2를 읽고 `geometry_arrays[*].elements`를 재사용한다. 모델과 송신기 순서를 다시 생성하거나 일반 Tube 계산식·두 번째 시리얼 계층을 추가하지 않는다. 측정 보정·OFF·맵 저장·펌웨어별 양자화 경계는 T5, 다중 정지/이동 목표점 동시 재생은 T6에 남아 있다.

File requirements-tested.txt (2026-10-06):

# T0/T2 validated existing environment: Windows, Anaconda Python 3.13.9, 2026-10-07.
# Core package snapshot, not a complete lockfile or a fresh-install verification.
# Optional GPU/k-Wave/CAD packages intentionally stay in their existing environments.
PySide6==6.9.2
pyvista==0.49.0
pyvistaqt==0.13.1
vtk==9.7.0
numpy==2.2.6
scipy==1.15.3
numba==0.62.1
matplotlib==3.10.9
levitate==3.0.0
pyserial==3.5

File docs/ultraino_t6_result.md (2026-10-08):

# T6 단면 조작·궤적 이송 — 2026-10-08

단면 클릭/드래그, 선택·전체 제어점의 XYZ 이동, 비동기 위상·음장·궤적 진단·내보내기,
최신 프레임 송신 큐를 구현했다. 소프트웨어 및 fake-serial 검증 완료이며 실제 터널 이송은 미검증이다.
Creo R2의 8면·8기판·256채널 방사면 좌표와 법선, T2 음장 및 T5 보정·맵·OFF 인코더를 유지했다.

2026-10-08 연속 이동 회귀 수정: 제어점 이동 때 단면 작업을 취소하고 숨기던 동작을 수정했다.
마지막 완성 단면을 유지하고 실행 중인 단면 작업이 끝나면 표시한 뒤 최신 위상으로 다시 계산한다.
음원 형상·보정·단면 설정이 바뀐 결과는 계속 거절하며, 하드웨어에는 최신 검증 위상만 송신한다.
자동 계산을 켜야 이동에 따른 위상과 단면이 갱신된다. 계산이 느리면 화면은 완성된 스냅샷 단위로 갱신된다.
`음장 → 음장 분석 → 단면 갱신 간격`에서 1~5000 ms를 직접 입력할 수 있다. 기본값은100 ms이며
프로젝트·Undo/Redo에 저장된다. 빠른 반응이 필요하면20~50 ms부터 조절한다. 이 값은 계산 시작의 최소 간격이고
실제 갱신은 계산 완료 속도에 제한된다. 실행 중인 계산은 간격 변경만으로 취소하지 않는다.
수정 후 T6 집중22 passed, 전체250 passed/4 skipped를 확인했다.
[수정 회귀 기록](../scratch/ultraino_migration/field_motion_fix_full_pytest.xml).
갱신 간격 UI까지 포함한 푸시 전 최종 전체 회귀는252 passed/4 skipped였다.
[최종 검증 기록](../scratch/ultraino_migration/t6_final_pytest.xml).

## 사용 방법

앱을 저장하고 다시 실행한다. `구성 → 제어점` 아래에 이동 조작이 있다.

1. 목록에서 이동할 제어점을 선택하고 `이동 대상`을 선택 제어점 또는 전체 제어점으로 정한다.
2. `단면 클릭·드래그로 이동`을 체크하고 XZ·YZ·XY 중 평면을 고른다.
   평면 위치는 기존 `음장 → 음장 분석`의 동일 이름 단면 위치 값이다.
   XZ는 Y 고정, YZ는 X 고정, XY는 Z 고정이며 터널 이송 축은 Z다.
3. 3D 뷰포트에서 클릭하거나 드래그한다. 이동 대상의 중심이 해당 세계 좌표로 이동하며
   여러 제어점 사이 간격과 각 트랩 종류·방향·가중치는 유지된다. 버튼을 놓은 최종 위치도 반영한다.
   체크를 해제하면 기존 왼쪽 클릭 선택 기능을 사용한다. 오른쪽 드래그 카메라 조작은 유지된다.
4. `이동 간격`과 X−/X+·Y−/Y+·Z−/Z+로 이동할 수도 있다.
   전체 제어점에는 비활성 제어점도 포함하지만 위상 계산은 활성 체크된 제어점만 사용한다.
5. 궤적을 생성하고 정방향·역방향 재생 버튼을 누른다. 선택·전체 제어점의 중심이 궤적을 따라 이동한다.
   첫 위치와 마지막 위치를 포함하며 이전 위치의 계산 및 실시간 송신이 끝나야 다음 위치로 진행한다.
   일시 정지와 `이동·계산 중지`는 대기 계산/프레임을 폐기한다. 이미 전송한 마지막 위상을 OFF로 바꾸지는 않는다.
6. 궤적 물리 진단과 내보내기는 별도 작업에서 수행하며 `이동·계산 중지`로 취소할 수 있다.
   오류·설정 변경·취소 결과는 저장하지 않는다. 이동 설정은 프로젝트·Undo/Redo에 저장한다.

기존 궤적 내보내기는 **waypoint마다 한 목표**의 파일이다. 여러 선택 제어점의 간격을 유지하는
동시 이송 재생과 구분한다. 다중 재생은 T4 혼합 목표를 유지하고 내보내기는 기존 단일 목표 계약을 유지한다.
음압·상대 강도 지표를 실물 부양 성공률로 표시하지 않는다.

## 계산과 송신 계약

- `motion.py`는 mm 단위 광선/평면 교차와 그룹 이동을 담당한다. 세계 좌표는 VTK의 근·원거리
  역투영으로 계산하고 HiDPI 배율과 Qt/VTK Y축 변환은 기존 이벤트 필터에서 적용한다.
  평행한 카메라 방향과 카메라 뒤쪽 평면은 이동 좌표를 만들지 않는다.
- `motion_ui.NumericalController`는 기존 `HologramController`의 QThread 종료·취소·최신 요청 관리를 재사용한다.
  작업별 실행 중 1개/최신 대기 1개만 보관한다. 작업자는 복사한 숫자·설정만 받으며 Qt/VTK 장면을 읽지 않는다.
  위상·진단·내보내기는 요청 번호와 입력 해시가 맞을 때만 GUI 스레드에서 결과를 적용한다.
  단면은 음원·보정·평면·표시 설정이 같으면 이전 완성 위상 스냅샷도 표시하고 최신 위상으로 후속 계산한다.
- live 위상 갱신은 최소 33ms 간격, 음장 요청은 사용자 지정 간격(기본100ms), 이동 렌더링은 33ms로 병합한다.
  느린 계산 중 드래그 요청은 최신 위치로 합친다. 궤적 재생은 이전 위상이 준비될 때까지 현재 waypoint를 유지한다.
  음장 계산 취소는 512개 수신점 단위, 궤적/진단 취소는 waypoint 및 Kinoforms 반복 경계에서 확인한다.
  Taichi 공통 복소 합산은 잠금으로 직렬화한다.
- `hardware.queue_phases`는 기존 공통 프레임 인코더로 보정→맵→양자화/OFF를 적용한다.
  실행 중 write 1개와 최신 대기 프레임 1개만 유지한다. 실시간 write는 별도 QThread이며
  기존 0.1초 write_timeout, 부분 쓰기/timeout 시 연결 종료 및 재시도 없음 원칙을 유지한다.
  큐는 최대 30Hz와 실제 프레임 길이의 8N1 선로 시간 중 느린 조건을 적용한다.
- 중지·연결 해제·설정 변경 시 대기 프레임은 폐기한다. 재연결 후 이전 세션의 완료 결과나
  프레임을 재송신하지 않는다. 이미 시작한 write는 되돌릴 수 없으며 로컬 write 성공은 보드 ACK가 아니다.
  수동 전송과 실시간 write가 겹치면 수동 전송은 실패 사유를 표시한다. write 완료 후 사용자가 다시 전송할 수 있다.
- 창 닫기는 계산 및 송신 작업이 끝난 뒤 진행한다. 저장 취소 시 창을 유지한다.

## 현재 PC에서의 검증

Anaconda Python 3.13.9, Intel UHD Graphics 620, 실제 Taichi Vulkan과 기존 C++ DLL을 사용했다.
NVIDIA CUDA와 실제 COM은 사용하지 않았다. 전체 회귀 **248 passed, 4 skipped**이며
[JUnit](../scratch/ultraino_migration/t6_pytest.xml)에 기록했다.
전체 회귀 후 첫 waypoint 포함 처리를 보완했고, 최종 T6 집중 검증 **20 passed**를 다시 확인했다.
[집중 검증 JUnit](../scratch/ultraino_migration/t6_motion_pytest.xml), [test_motion.py](../tests/test_motion.py)에 기록했다.

확인 항목은 세 평면 교차/회전 카메라 세계 좌표, 단일/전체 이동·간격·트랩 메타데이터 보존,
드래그 해제 위치, 최신 요청/복사 입력/취소, 정방향·역방향·최종 위상, 느린 계산·write 중 waypoint 유지,
프로젝트 설정의 원자적 복원, GUI 스레드에서의 음장 표시, 비동기 진단·파일 인코딩 일치,
부분 write/timeout/재연결/창 닫기다.

실제 데스크톱 검증 창에서 Creo256채널의 혼합 Twin/Standing Wave·단면 표시·전체 이동 컨트롤을 확인했다.
드래그 후 X=30.47mm, Y=0, 중심 Z=18.28mm로 이동하고 두 점의 Z 간격20mm를 유지했으며
Vulkan 계산과 fake frame 6건을 확인했다. [드래그 기록](../scratch/ultraino_migration/t6_drag_result.json),
[수정한 버튼 배치 캡처](../scratch/ultraino_migration/t6_ui.png),
[마지막 창 실행 기록](../scratch/ultraino_migration/t6_ui_result.json)을 보존했다.

### 갱신 스트림 실측

[재현 도구](../scratch/ultraino_migration/verify_t6_updates.py)는 혼합 2트랩·256채널·12회 고정 반복을
warm 상태에서 nominal 33ms 타이머로 30회 요청했다. 실제 Qt 타이머 지연과 작업 생성 비용도 포함한다.
[측정 원본](../scratch/ultraino_migration/t6_updates_result.json)은 fake serial 결과이며 실제 선로/ACK 측정이 아니다.

| 엔진 | 요청/적용/프레임 | 스트림 종료까지 | 마지막 응답 | 적용 계산 시간 |
|---|---|---|---|---|
| C++ | 30 / 30 / 30 | 1.430초 | 23.84ms | 약17.93~20.93ms |
| Taichi Vulkan | 30 / 1 / 1 | 1.588초 | 78.77ms | 마지막 계산71.83ms |

Vulkan은 29개 요청을 최신 요청으로 병합했고 최종 phasor 오차는 CPU 기준1.83e-15 미만이다.
마지막 프레임은 기존 live 인코더와 일치했다. 이 때문에 재생은 계산/송신 완료를 기다리도록 했다.
현재 작은 혼합 목표 문제에는 C++이 더 빠르다. nominal 30Hz 요청을 실제 보드의 30Hz 지속 갱신으로 해석하지 않는다.
230400 baud·258byte·8N1의 선로 시간만 약11.2ms이며, 장치/드라이버와 계산에 따라 더 느리다.

## 재현 및 다음 단계

저장소 루트에서 실행한다.

```powershell
$env:PYTHONPATH='src'
$env:QT_QPA_PLATFORM='offscreen'
$env:PYTHONIOENCODING='utf-8'
& 'C:/Users/line0/anaconda3/python.exe' -m pytest -q --junitxml=scratch/ultraino_migration/t6_pytest.xml
& 'C:/Users/line0/anaconda3/python.exe' scratch/ultraino_migration/verify_t6_updates.py
```

`verify_t6_ui.py`는 visible Qt 창을 띄우지만 포트를 열지 않고 fake serial만 사용한다.
실제 창 검증에는 QT_QPA_PLATFORM=offscreen을 해제한다. 검증 창은 180초 후 자동으로 닫히며
scratch/ultraino_migration/t6_close.request 파일로 먼저 종료할 수도 있다.

다음 실물 단계는 T7이다. 실제 컨트롤러/펌웨어·DATA/뱅크 배선·OFF/파형·지속 갱신률,
유효 음향 개구·입자 물성·절대 음압 보정을 확인한 사용자 요청 하드웨어 작업에서
단일 부양→Z축 이송→정지 유지→다중 입자 순서로 검증한다.
현재 작업은 패키지 설치·CAD 재생성·DLL 재빌드·backup 갱신·commit/push를 수행하지 않았다.

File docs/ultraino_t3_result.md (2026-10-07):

# T3 고정 위상 방사력·복원성 분석 결과

2026-10-07. T3 구현과 소프트웨어 검증을 완료했다. **Creo R2의 8면·8기판·기판당 32개, 총 256채널**에서 송신 위상·진폭을 고정하고 평가 위치만 이동하여 고르코프 퍼텐셜, 방사력, 전체 3×3 복원행렬을 계산한다. 다음은 [계획의 T4 Kinoforms·다중 트랩](ultraino_migration_plan.md)다.

## 사용하는 방법

1. 기존 Creo 터널 프리셋을 추가하고 제어점을 만든 뒤 현재 공통 음향 설정으로 위상을 계산한다. 방향성 모델에는 확인된 유효 음향 개구가 필요하다.
2. `음장 → 고정 위상 방사력·복원성 분석`을 누른다. 선택한 제어점이 평가 중심이 되며 선택이 없으면 첫 제어점을 사용한다. 아직 계산하지 않았거나 음향 설정이 변경된 경우 재계산 안내를 표시한다.
3. 분석 창에서 중심 XYZ, 축별 범위 ±, 홀수 표본 수, 미분 간격 h, 수렴 허용 오차, 중력 XYZ와 입자 물성을 입력한다. 위치를 변경해도 송신 위상을 재집속하지 않는다.
4. `고정 위상으로 분석`을 누르면 힘·중력 가정 합성, 상대 음압, 퍼텐셜, 축별 복원 스티프니스 곡선을 볼 수 있다. 중심의 전체 복원행렬과 부호를 가진 고유값도 표시한다. 결합 방향의 비복원성을 대각 성분만으로 숨기지 않는다.
5. `분석 JSON 저장`은 고정한 송신기 위치·법선·위상·진폭·개구·공통 음향 설정, 물성 출처, 미분 수렴, 모든 곡선, 실제 엔진과 판정 한계를 함께 저장한다. 입력 변경·실패·취소 시 이전 결과의 저장을 해제한다.

기본 입자 반경 **0.25mm**는 소프트웨어 예시이며 실제 부양 대상의 크기가 아니다. 밀도 **25kg/m³**, 음속 **2350m/s**는 설치된 Levitate의 styrofoam 기본 물성을 참고한 예시다. 물성 구분과 출처를 필수로 보존하며, 반경·밀도·음속 또는 압축률을 직접 입력할 수 있다. 직접 압축률은 음속·밀도로 계산한 값을 대체한다. 실제 대상의 물성과 출처는 아직 미확정이다.

## 계산 계약과 판정 범위

T2의 `FieldConfig`와 `PhaseEngine.calculate_field_slice()`를 재사용한다. Creo 방사면 좌표와 실제 내향 법선, 소프트웨어 채널 순서를 유지하며 새로운 전파 엔진을 만들지 않았다. `FieldSnapshot`은 배열을 복사하고 읽기 전용으로 보존한다. 여기의 위상은 현재 계산된 소프트웨어 위상이며 실측 채널 보정·펌웨어 양자화 후의 실제 음장을 재현한 값이 아니다.

위치·반경 API는 mm, 내부 미분은 m, 위상은 rad다. 복소 음압은 peak phasor 규약이다. 입자 체적 V, 입자/매질 압축률 κp/κ, 밀도 ρp/ρ, 각주파수 ω를 사용한다.

```text
κ = 1 / (ρ c²), κp = 1 / (ρp cp²) 또는 직접 입력
f1 = 1 − κp / κ
f2 = 2(ρp − ρ) / (2ρp + ρ)
M1 = V f1 κ / 4
M2 = V (3/8) f2 / (ρ ω²)
U = M1 |p|² − M2 (|∂xp|² + |∂yp|² + |∂zp|²)
F = −∇U
Kij = −∂Fi/∂xj = ∂²U/(∂xi ∂xj)
conditional_total_force = nominal_acoustic_force + mass × gravity
```

원본 [CalcField.java](../../simulations/Ultraino/AcousticFieldSim/src/acousticfield3d/algorithms/CalcField.java)의 계수와 4차 정확도 1차 미분 스텐실을 옮겼다. 압력 기울기와 힘의 미분 계수는 `[1,−8,8,−1]/(12h)`, 위치는 `[-2h,−h,h,2h]`다. K 대각 성분은 5점 4차 정확도 2차 미분, 비대각 성분은 두 축의 1차 스텐실을 곱한 16점 혼합 미분이다. 혼합 성분은 양쪽에 같은 값을 기록하므로 행렬의 대칭 자체가 독립적인 물리 검증은 아니다. 전체 행렬은 Levitate의 힘을 별도로 미분한 기준과 비교했다.

Ultraino `calcForceGradients()` 및 Levitate `RadiationForceStiffness`는 **+∂F/∂x**를 반환한다. 이 창의 복원행렬은 **−∂F/∂x**다. Levitate의 `GorkovGradient`는 ∇U, `GorkovLaplacian`은 Hessian 대각 성분이다. 같은 입자·매질·음장으로 고르코프 계열을 비교했으며, 진행파 산란 항이 추가된 RadiationForce와 동일한 모델로 취급하지 않는다. 정의와 적용 범위는 [Levitate 공식 필드 문서](https://levitate.readthedocs.io/en/stable/api_docs/fields.html)를 참고한다.

각 분석에서 **h, h/2, h/4**로 모든 축의 힘·대각 스티프니스와 중심 전체 행렬을 계산한다. 최종 곡선은 h/4 값이며 두 번의 상대 변화가 모두 입력 허용 오차 이내일 때 수렴으로 표시한다. 초기 h는 파장의 1/8 이하여야 한다. 중심 행렬 변화의 spectral norm 최대값 두 배를 수치 부호 판정 여유로 사용한다. 이는 경험적 수치 변화 지표이며 엄밀한 오차 상한이나 물리 모델 오차가 아니다.

모든 고유값이 양의 판정 여유보다 크면 `restoring`, 음의 여유보다 작은 고유값이 있으면 `non_restoring`, 중립·수치 불확실성·수렴 실패는 `unresolved`다. **ka≤0.3은 이 소프트웨어의 보수적 진단 기준**이며 보편적인 물리 경계가 아니다. 이를 벗어나면 곡선은 볼 수 있어도 복원 부호 판정은 보류한다. 음원과의 거리가 입자 반경 또는 모델 최소 거리 이하인 스텐실, NaN/Inf와 잘못된 입력은 거절한다. 임의로 작게 잡은 h가 항상 더 정확한 것은 아니므로 세 간격의 결과를 확인한다.

**음압은 여전히 미보정 상대값**이다. `N*`, `J*`, `N*/m`는 상대 음압 1을 1Pa로 간주한 명목 계산 단위다. 중력 mg 자체는 입력한 물성에서 계산한 N이며, 음향 힘과 합성한 값은 같은 명목 음압 스케일을 가정한 결과다. 평형에는 XYZ 잔류력 모두가 0이어야 한다. 이 창은 잔류력과 가정 곡선을 제공하지만 `pressure_calibrated=false`, `gravity_equilibrium_status=unavailable_uncalibrated_pressure`를 유지한다. 실제 평형점을 자동 탐색하거나 부양 성공을 선언하지 않는다. `valid=true`는 수치 계산 성공을 뜻하며 실험 검증을 뜻하지 않는다.

작은 구의 비점성 고르코프 근사와 T2 자유 음장을 사용한다. 진행파 산란력·점성·기구물 반사/차폐를 포함하지 않는다. 국소 복원 부호만으로 동적 안정성이나 실험 성공률을 표시하지 않는다. 기존 궤적의 `relative_stiffness_norm` 및 기본 1mm styrofoam 진단은 별도 경로로 남아 있으며 T3 판정과 같지 않다.

## 구현 파일과 실행 환경

| 파일 | 이번 역할 |
| --- | --- |
| [force_analysis.py](../src/acousticstudio/force_analysis.py) | `ParticleConfig`, `AnalysisSettings`, `FieldSnapshot`, `ForceAnalyzer`. 위상 고정, 계수·미분·전체 K·수렴·명목 중력 잔류력·JSON 변환. |
| [force_analysis_ui.py](../src/acousticstudio/force_analysis_ui.py) | Qt 분석 창, 실제 QThread worker, 입력·곡선·행렬·출력·취소 및 종료 관리. |
| [app.py](../src/acousticstudio/app.py) | 음장 탭 버튼, 위상 계산 여부 확인, GUI 스레드에서 CAD 입력을 고정, 분석 설정 저장·복원 및 Undo/Redo. |
| [test_force_analysis.py](../tests/test_force_analysis.py) | 해석식·결합 부호·Levitate·강체 변환·수렴/실패·취소 검증. |
| [test_force_analysis_ui.py](../tests/test_force_analysis_ui.py) | 실제 worker 계산·결과 저장·입력 변경·취소·창 닫기·Escape·오류 처리. |
| [test_creo_geometry.py](../tests/test_creo_geometry.py) | 분석 설정의 저장·Undo/Redo·이전 파일 기본값·잘못된 설정에서 장면 보존. |
| [THIRD_PARTY_NOTICES.md](../THIRD_PARTY_NOTICES.md) | Ultraino 파생 계산의 MIT 저작권 고지 보존. |

Qt/VTK actor 접근은 메인 스레드에서 스냅샷을 만들 때 완료한다. worker에는 순수 수치 데이터만 전달하고 결과 신호로 GUI를 갱신한다. 취소 Event를 수신점 chunk마다 확인한다. 계산 중 닫기/Escape는 취소를 요청하고 thread가 끝난 뒤 창을 닫는다. 실패·취소는 부분 결과를 정상 결과로 저장하지 않는다. 분석 설정은 프로젝트 `force_analysis_settings`에 저장하며, 키가 없는 이전 프로젝트는 명시된 예시 기본값을 사용한다.

기존 **Anaconda Python 3.13.9**, NumPy/SciPy/Levitate/PySide6/matplotlib과 T2 가속 계층을 재사용했다. 추가 설치·가상환경 생성·DLL 재빌드는 필요하지 않았다. 필수 의존성 10개와 별도 CAD 환경은 그대로다. 전파 행렬 생성은 CPU, 복소 합산은 선택 엔진이며 전체 계산의 GPU 이식이나 성능 향상 측정은 이번 범위에 포함하지 않는다.

## 실행한 검증과 재현

전체 테스트 **143 passed, 3 skipped, 1 warning (8.98s)**. [JUnit 기록](../scratch/ultraino_migration/t3_pytest.xml). skip 3개는 현재 설치본에서 사용할 수 없는 PyTorch CUDA, warning은 기존 Taichi locale 사용 중단 경고다.

- SI 계수와 압축률 직접 입력, 독립 정상파 해석식의 힘·복원 부호, 4차 미분 수렴을 확인했다.
- 대각 K가 모두 양수여도 결합 방향 고유값이 음수인 saddle을 구별했다. 일정 중력의 행렬 불변성과 XYZ 명목 평형 조건, 실제 음압 미보정 판정 보류를 확인했다.
- 무지향·sinc·피스톤에서 설치된 Levitate의 U/F/대각 K와 전체 힘 미분 기준을 비교했다. 4채널 합성 조건의 벡터/행렬 상대 오차는 각각 아래 표와 같다. 방향성 개구 **4.5mm는 합성 시험값이며 실제 송신기 개구가 아니다**.

| 같은 모델 기준 비교 | U 상대 오차 | F 상대 오차 | 전체 K 상대 오차 |
| --- | --- | --- | --- |
| 무지향 | 3.00e−9 | 2.44e−8 | 2.10e−5 |
| Ultraino sinc | 1.58e−6 | 2.77e−5 | 2.66e−5 |
| 원형 피스톤 | 4.16e−7 | 1.74e−5 | 2.05e−5 |

- 실제 Creo 256채널에 세 모델을 적용하여 고정 위상에서 강체 회전·이동 후 `F'=R F`, `K'=R K Rᵀ`를 검증했다.
- 세 모델 × 네 엔진 요청 **12건**의 전체 분석을 비교했다. C++와 실제 Taichi CUDA는 CPU 기준과 일치했고 최대 상대 오차는 F 약 **1.67e−12**, K 약 **5.34e−11**였다. PyTorch 요청은 CUDA 불가 사유와 함께 CPU로 전환됐다. [수치 비교·입력·환경·해시 JSON](../scratch/ultraino_migration/t3_numerical_result.json)에 기준값과 실행 시간을 보존했다. 시간은 warm-up이 포함된 단발 검증 기록이며 성능 벤치마크가 아니다.
- 실제 Qt 메인 창에서 Creo 프리셋·현재 위상 guard·C++ 분석·JSON 저장·설정 복원을 확인했다. 256개 위상이 분석 전후 같았고 시리얼은 연결하지 않았다. [Qt 실행 JSON](../scratch/ultraino_migration/t3_ui_result.json), [분석 스냅샷](../scratch/ultraino_migration/t3_example_analysis.json), [창 캡처](../scratch/ultraino_migration/t3_force_dialog.png), [곡선 PNG](../scratch/ultraino_migration/t3_force_curves.png)를 보존하고 그림을 직접 확인했다. Qt offscreen 3D 뷰포트 캡처는 제외했다.

Qt 예시의 터널 중심·Twin Trap·무지향·예시 입자는 수렴하고 명목 K 고유값 `[3.72e−5, 8.64e−5, 3.85e−4] N*/m`의 국소 복원 부호를 보였다. 그러나 중심의 가정 잔류력 Z는 약 `−1.60e−8 N*`였으며 중력 평형이 아니다. 이 결과를 실제 대상의 부양 검증으로 사용하지 않는다.

```powershell
# AcousticStudio 루트에서 기존 앱 환경을 재사용한다.
$env:PYTHONPATH = 'src'
$env:QT_QPA_PLATFORM = 'offscreen'
$env:PYTHONIOENCODING = 'utf-8'
& 'C:/Users/line0/anaconda3/python.exe' -m pytest tests -q -rs --junitxml=scratch/ultraino_migration/t3_pytest.xml
& 'C:/Users/line0/anaconda3/python.exe' scratch/ultraino_migration/audit_t3_numerics.py
& 'C:/Users/line0/anaconda3/python.exe' scratch/ultraino_migration/verify_t3_ui.py
& 'C:/Users/line0/anaconda3/python.exe' scratch/ultraino_migration/verify_t3_static.py
```

[정적 검사 기록](../scratch/ultraino_migration/t3_static_result.json): Python 37개 AST, 문서 13개 UTF-8·로컬 링크 136개, T2 native 소스/DLL 및 수치 비교 입력 해시 일치, `git diff --check`를 확인했다. 실제 보드 송신·부양, CAD 재생성, k-Wave 실행은 수행하지 않았다. backup/commit/push는 갱신하지 않았다.

## T4 구현에 사용한 인계 기준

T0~T3는 이후 사용자 요청으로 [00de06b 커밋](https://github.com/ekkukdl/AcousticStudio/commit/00de06b6607c9a822d11f38f1c8f563095d41ae1)에 기록하여 main에 push했다. 아래 기준에 따른 T4 및 T5도 소프트웨어 검증을 완료했으며 현재 다음 소프트웨어 단계는 T6다. 최신 인계는 [T5 결과](ultraino_t5_result.md)를 따른다.

1. AGENTS.md, 계획, T2/T3 결과를 읽고 `git status --short`를 확인한다. T4 구현은 기존 형상·전파·분석 경로를 재사용한다.
2. 원본 [Kinoforms.java](../../simulations/Ultraino/AcousticFieldSim/src/acousticfield3d/algorithms/Kinoforms.java)를 읽고 `hologram.py`에 가상점 생성과 IBP를 추가한다. PhaseEngine 진입점과 T2 전파 행렬을 연결한다. 배열 로더·전파 엔진·시리얼 계층을 중복 작성하지 않는다.
3. Focus → 다중 Focus → Twin/Standing Wave 순서로 구현한다. Java 가상점 축/위상을 현재 Z축 터널 좌표계로 명시적으로 변환한다. 원본의 가상점 간격을 현재 mm/m 계약에 맞춘다. 초기 위상·반복 수·목표 진폭/상대 위상 제약을 재현 가능한 입력으로 남긴다.
4. 보드 지원이 확인되지 않은 진폭 제어를 전제로 삼지 않는다. phase-only 제약과 고정 음원 이득을 구분하고 영 복소값/영 진폭을 처리한다. 형상·법선·개구·공통 모델·목표점 변경 시 캐시를 무효화한다.
5. 결과의 균일도·잔차·256채널 실행 시간을 기록한다. 새 위상을 `FieldSnapshot`으로 고정하여 목표점마다 T3의 부호 있는 전체 K·수렴을 평가한다. 여러 음압 초점이나 stiffness norm의 양수만으로 다중 부양을 선언하지 않는다. 실시간 이동 중의 매 지점 재집속과 고정 위상 변위 스캔을 구분한다.
6. 계산은 취소 가능한 수치 worker에서, Qt/VTK 업데이트는 메인 스레드에서 처리한다. T3의 입력/결과 구조와 프로젝트 호환성·실패 처리를 재사용한다. T4 소프트웨어 검증은 COM 연결·실물 송신 없이 진행한다.

실측 유효 개구·대상 입자 물성·구동 조건별 음압/위상 보정, 물리 채널 맵과 펌웨어 확정은 여전히 남아 있다. 보정 데이터와 OFF·양자화는 T5, 조작/이송 및 실험 수용 기준은 T6/T7에서 이어간다.

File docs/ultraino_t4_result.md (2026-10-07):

# T4 Kinoforms·다중 트랩 구현 및 검증 결과

2026-10-07. T4 구현과 소프트웨어 검증을 완료했다. **Creo R2의 8면·8기판·기판당 32개, 총 256채널**을 그대로 사용하며 Focus/Twin/Standing Wave를 함께 설계한다. 송신기 이득을 고정하고 위상만 조절한다. 다음은 [계획의 T5 통신·캘리브레이션](ultraino_migration_plan.md)다. 다중 음압 제약을 구현한 결과이며 실제 다중 입자 부양을 확인한 결과는 아니다.

## 앱에서 확인하는 순서

1. `구성 → 배열 형태 → Creo 8면 터널 · 8기판 × 32채널`을 선택하고 배열을 추가한다. 제어점을 두 개 이상 만들고 목록의 체크를 켠다. 검증 예시는 `(-10,-3,5)`, `(8,4,-7)` mm다. 한 점도 계산할 수 있으며 체크를 끈 점은 설계에서 제외된다.
2. `음장 → 공통 음향 모델`을 확인한다. 실측 유효 개구가 없으면 무지향 모델부터 사용한다. CAD 외경은 유효 음향 개구로 대체하지 않는다. 아래 방향성 비교의 4.5mm 반경은 검증용 가정이다.
3. `음장 → 다중 트랩 설계 (Kinoforms)`를 연다. 활성 제어점별 Focus/Twin/Standing Wave, 상대 목표 음압 가중치, 세계 좌표 방향 XYZ를 입력한다. 타입을 바꾸면 Twin은 X, Standing Wave는 터널 Z가 기본 방향이 된다. 방향은 내부에서 단위 벡터로 정규화되며 영 벡터는 거절한다.
4. 재현 비교는 최대 반복 50회, 위상 변화 허용값 0, 초기 `0 위상`으로 시작한다. 기본 설정은 최대 50회·허용값 1e−6rad이며 정체 시 조기 종료한다. `새 제어점·단일 궤적 기본 트랩`은 기존 표 행의 타입을 바꾸지 않는다.
5. `Kinoforms 계산`을 누르고 실제 엔진, 잔차 곡선과 가중 음압 균일도를 확인한다. 잔차가 단조 감소하거나 작은 값에 도달한다는 보장은 없다. 위상 정체도 최적해·복원성·부양 성공을 뜻하지 않는다.
6. 표에서 검사할 트랩을 선택한 뒤 `선택 트랩의 고정 위상 분석`을 연다. 후보 위상을 배열에 적용하지 않아도 T3에서 XYZ 힘, 전체 K의 부호와 미분 수렴을 확인할 수 있다. 다른 점도 선택해 각각 검사한다. 실제 입자 물성은 별도로 입력해야 한다.
7. `현재 배열에 위상 적용`으로 메인 위상·색상·Kinoforms 모드와 제어점별 설정을 갱신한다. `설계 JSON 저장`은 초기/최종 위상과 입력 스냅샷을 함께 기록한다. 설정 변경·실패·취소 시 이전 결과의 적용/저장은 해제된다.
8. 프로젝트 저장·복원 및 Undo/Redo는 설정·목표·활성 체크를 유지한다. 메인 Kinoforms 모드에서 제어점을 이동한 뒤 계산하면 새 위치를 반영한다. 기존 자동 계산이 꺼져 있다면 위상 계산을 다시 실행한다. 기존 Focus/Twin Trap/Vortex Trap 경로도 유지한다.

계산 중 취소·닫기·Escape는 현재 수치 호출이 끝난 뒤 thread 종료를 기다린다. COM 연결 없이 이 순서를 확인할 수 있다. [설계 창 예시](../scratch/ultraino_migration/t4_design_dialog.png), [잔차·음압 그래프](../scratch/ultraino_migration/t4_constraints.png), [혼합 설계 JSON](../scratch/ultraino_migration/t4_example_design.json)을 남겼다.

## 계산 계약과 원본 대응

원본은 [Kinoforms.java](../../simulations/Ultraino/AcousticFieldSim/src/acousticfield3d/algorithms/Kinoforms.java)다. T2의 공통 Green 행렬과 엔진별 복소 합산을 재사용한다. 별도 전파 모델·시리얼 컨트롤러·CAD 생성기는 추가하지 않았다. [MIT 고지](../THIRD_PARTY_NOTICES.md)를 보존했다.

| 입력/출력 | 계약 |
| --- | --- |
| `TrapTarget` | 세계 좌표 `position_mm`, `trap_type`, 양의 `weight`, 비영 `direction` |
| `HologramSettings` | 반복 1~2000, 위상 허용값 0~0.1rad, 기본 타입, `zeros/current` 초기화 |
| 음원 | CAD 방사면 mm 좌표·실제 법선·소프트웨어 순서의 고정 상대 이득·확인된 개구 |
| 전파 | `FieldConfig`와 T2 모델; 내부 거리는 m, 주파수 Hz, 위상 rad |
| 구동 | 이득 양수 채널은 복소 구동 크기 1, 이득 0은 모델상 0. 조절 가능한 진폭은 구현하지 않음 |
| 결과 | 소프트웨어 순서 위상, 가상점/그룹/부호/가중치, 초기/최종 잔차, 반복 이력, 실제 backend/전환 사유 |
| 단위 | `relative_uncalibrated`, `pressure_calibrated=false`. 목표 가중치는 Pa가 아님 |

Java→AcousticStudio는 `(x,y,z) → (x,−z,y)`인 오른손 변환이다. 원본 Y는 현재 터널 Z가 되고 원본 Z는 −Y가 된다. `JAVA_TO_STUDIO`로 축과 Twin 회전 방향을 검증했다. GUI 방향은 변환된 세계 좌표를 직접 입력하며 트랩 타입을 제어점 색으로 인코딩하지 않는다.

| 타입 | 가상점 | 그룹 내 상대 위상 |
| --- | --- | --- |
| Focus | 중심 한 점 | 자유 앵커 위상 |
| Twin | 중심 ± `(λ/1.5) × direction` | 0, π |
| Standing Wave | 중심 ± `(λ/2) × direction` | 0, π |

원본 `sep`는 중심에서의 **오프셋**이다. 두 점의 전체 간격은 각각 2λ/1.5와 λ이며 다시 반으로 나누지 않는다. λ는 공통 설정의 c/f에서 계산한다. 가상점 중복·음원 근접점은 거절한다. 최대 목표 256개와 행렬 원소 2,000,000개 제한으로 과도한 입력을 막는다.

`H = G × fixed_source_gain`으로 두고 `p=Hq` 전방 투영 → 각 그룹 첫 가상점의 위상을 앵커로 한 상대 음압/π 제약 `d` → `Hᴴd` 공액 역전파 → 활성 채널 크기 1 정규화를 반복한다. 영/근영 목표 음장은 이전 앵커(초기 1+0j)를 유지하고, 영 역전파 채널은 이전 위상을 보존한다. 전체 영 음장이나 비유한 결과는 성공으로 반환하지 않는다.

잔차는 양의 공통 상대 음압 스케일 α를 적합한 `||p−αd||/||p||`다. 균일도는 `min(|p|/weight)/max(|p|/weight)`다. 두 값은 음압 제약의 지표다. 허용값은 공통 위상 회전을 제거한 채널별 위상 변화의 최댓값에 적용하며, 목표 잔차 허용값으로 사용하지 않는다.

단일 전파 행렬 캐시는 음원 좌표·법선·고정 이득·개구·모델 설정 및 목표 위치/타입/가중치/방향을 해시한다. 반복 수·초기화 설정은 행렬 자체를 바꾸지 않지만 결과 적용용 입력 해시에는 포함한다. 새 초기 위상으로 같은 행렬을 재사용할 수 있다. `snapshot.initial_phases_rad`는 실제 계산에 사용한 초기값을 기록한다.

## 연결 파일과 비동기 처리

| 파일 | 역할 |
| --- | --- |
| [hologram.py](../src/acousticstudio/hologram.py) | 불변 설정/목표, 가상점, IBP, 지표, 캐시, 취소 |
| [phase_engine.py](../src/acousticstudio/phase_engine.py) | `calculate_hologram` 및 기존 `calculate_phases`의 Kinoforms 진입점 |
| [hologram_ui.py](../src/acousticstudio/hologram_ui.py) | 수치 worker/controller, 설계 창, 결과 JSON, T3 후보 분석 |
| [app.py](../src/acousticstudio/app.py) | 기존 음장 탭 연결, 메인 계산·색상·저장·Undo/Redo |
| [test_hologram.py](../tests/test_hologram.py), [test_hologram_ui.py](../tests/test_hologram_ui.py) | 독립 반복 기준·경계조건·엔진/궤적 연결·실제 Qt thread 수명 검증 |
| [test_creo_geometry.py](../tests/test_creo_geometry.py) | 기존 저장과 트랩 메타데이터·활성 체크·비원점 복원 회귀 |

수치 worker에는 `FieldSnapshot`, `TrapTarget`, 설정, 취소 Event만 전달한다. Qt/VTK actor와 위젯 읽기·갱신은 GUI 스레드에서 한다. controller는 한 번에 한 worker만 실행하고 마지막 대기 요청만 보존한다. 이전 요청은 취소하고 요청 번호가 일치하는 결과만 전달한다. 메인 창은 현재 입력 해시까지 다시 비교하여 계산 중 위치/모델이 바뀐 결과를 폐기하고 새 결과 전 송신을 보류한다. 입력 변경이 계산 요청을 발생시키지 않은 경우에는 사용자가 다시 계산해야 한다.

프로젝트에는 `hologram_settings`, 제어점 `hologram_target={trap_type,weight,direction}`, `active`를 저장한다. 새 필드를 먼저 검증한 뒤 장면을 변경한다. 이전 파일의 누락 필드는 기본 Focus/50회/0 초기화 및 활성 상태로 복원한다. 비원점 구의 로컬 mesh 중심과 actor 이동을 중복 적용하던 복원 오류도 수정했다.

**프로젝트 복원은 저장된 설정으로 위상을 재계산한다.** `현재 위상` 초기화는 당시 actor의 위상을 사용하며 위상이 없으면 0이다. 프로젝트에는 초기 위상 배열과 최종 해를 고정 저장하지 않으므로 이 옵션의 정확한 반복 재실행은 설계 JSON의 초기 스냅샷으로 수행한다. 기본 0 초기화의 반복성·프로젝트 복원을 확인했다.

정확한 설계 재실행의 API 형태는 다음과 같다. 메인 GUI에 설계 JSON을 불러오는 별도 기능은 추가하지 않았다.

```python
import json
from pathlib import Path
from acousticstudio.field_model import FieldConfig
from acousticstudio.hologram import HologramSettings, TrapTarget
from acousticstudio.phase_engine import PhaseEngine

data = json.loads(Path("design.json").read_text(encoding="utf-8"))
snapshot = data["snapshot"]
result = PhaseEngine().calculate_hologram(
    snapshot["sources_mm"], [TrapTarget(**item) for item in data["targets"]],
    snapshot["amplitudes"], field_config=FieldConfig(**snapshot["field_config"]),
    normals=snapshot["normals"], aperture_radii_mm=snapshot["aperture_radii_mm"],
    settings=HologramSettings(**data["settings"]), initial_phases=snapshot["initial_phases_rad"],
)
```

기존 궤적 위상 생성/최적화/내보내기는 같은 Kinoforms 설정을 전달하지만 **웨이포인트별 한 이동 목표**를 계산한다. 현재 초기 위상 배열은 이 경로에서 전달하지 않아 각 단계가 0에서 시작한다. 동시 다중 입자 궤적 UI·일반 드래그 큐·궤적 작업 전체의 비동기화는 T6 범위다. Vortex/BFGS/DivTrans 이식도 후속 범위다.

## 실행한 검증과 해석 범위

전체 pytest는 **171 passed, 3 skipped, 1 warning, 12.58s**였다. 3개 skip은 기존 PyTorch CUDA 전용 사례이며 CUDA 없는 현재 build에서 제외했다. warning은 기존 Taichi locale 항목이다. [JUnit 기록](../scratch/ultraino_migration/t4_pytest.xml)에 174개 사례를 남겼다. 새 회귀는 독립 스칼라 실수/허수 IBP, 단일 초점 공액 위상, 고정 불균일 이득/영 채널, 혼합 목표, 가중치·중복·근접·잘못된 설정·취소, 강체 변환, 캐시 무효화와 GUI thread 최신 요청 처리 등을 확인한다.

[원본 Java 비교 도구](../scratch/ultraino_migration/verify_t4_java.py)는 **수정하지 않은 원본 Kinoforms.java**를 기존 OpenJDK 25.0.4.1로 컴파일했다. 4음원·2목표·고정 단위 이득·초기 위상 `(0.2,0.9,2.4,3.2)` rad·12회 `iterate(true)` 조건으로 비교했다. 수학/엔티티/공통 점음원 전파 어댑터를 사용했으며 원본 전체 앱·렌더러·물성 모델의 통합 비교는 아니다. 원본 가상점과 반복 알고리즘을 실제 실행한 비교다.

| 타입 | 공통 위상 정렬 후 최대 phasor 오차 |
| --- | --- |
| Focus | 7.12e−8 |
| Twin | 1.06e−7 |
| Standing Wave | 2.05e−7 |

Java float32와 Python float64 차이를 허용했다. 원본 SHA256과 결과는 [Java 비교 기록](../scratch/ultraino_migration/t4_java_result.json)에 있다.

[수치 점검](../scratch/ultraino_migration/audit_t4_numerics.py)은 Creo256채널·두 예시 목표·50회 고정 반복으로 3전파 모델 × 3타입 × 4엔진 요청 **36건**을 비교했다. CPU/C++/실제 Taichi CUDA가 일치했고 Torch 요청은 CPU로 전환했다. 최대 공통 위상 정렬 phasor 오차 **2.89e−14**, 복소 음장 상대 오차 **1.44e−15**다. 모델·엔진·캐시·시간·해시는 [수치 기록](../scratch/ultraino_migration/t4_numerical_result.json)에 있다.

동일 스냅샷의 T3 고정 위상 분석 **18건**에서 h·h/2·h/4 수렴, 전체 K와 힘, 미보정 중력 평형 보류를 기록했다. 예시 반경 0.25mm·밀도 25kg/m³·음속 2350m/s EPS 조건에서 두 목표 모두 Focus/Twin은 `non_restoring`, Z Standing Wave는 `restoring`이었다. 이는 해당 목표·이득·입자·자유 음장 조건의 국소 부호 결과다. 음압 미보정 상태의 N*·J* 가정값이며 실제 XYZ 힘 평형이나 부양을 확인하지 않았다. 모든 사례는 `unavailable_uncalibrated_pressure`를 유지했다. Focus의 높은 균일도도 복원성의 근거로 쓰지 않는다.

캐시 사용 단일 CPU 점음원 사례는 4.4~8.6ms였다. 통제된 벤치마크가 아닌 검증 실행의 시간이며 다른 작업 부하·초기 컴파일·작은 행렬의 GPU 호출 비용이 포함될 수 있다. Taichi 첫 Focus는 kernel 컴파일을 포함했다. 1~2ms 성능을 약속하지 않는다.

[실제 Qt 메인 창 점검 도구](../scratch/ultraino_migration/verify_t4_ui.py)는 Creo256채널/C++에서 세 타입 및 Twin+Standing Wave 혼합 계산·적용, 선택 후보 T3 worker, JSON 저장, 메인 최신 입력 검증·재계산·캐시, 설정/목표/비활성 체크 복원, 계산 중 창 종료를 실행했다. [Qt 기록](../scratch/ultraino_migration/t4_ui_result.json)에 모두 남겼다. 캡처는 설계 창·그래프를 확인했고 offscreen 3D 뷰포트는 시각 검증하지 않았다. serial은 연결하지 않았고 실제 송신 호출이 발생하면 실패하도록 했다.

자유 음장과 작은 구 비점성 고르코프 모델을 사용한다. 기구물 반사·차폐·점성·진행파 산란은 포함하지 않는다. 실측 유효 개구·대상 입자·구동 조건별 음압/위상 보정은 아직 없다. 이득 0은 계산상의 비활성 채널이며 실제 하드웨어 OFF 전송과 구분한다.
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

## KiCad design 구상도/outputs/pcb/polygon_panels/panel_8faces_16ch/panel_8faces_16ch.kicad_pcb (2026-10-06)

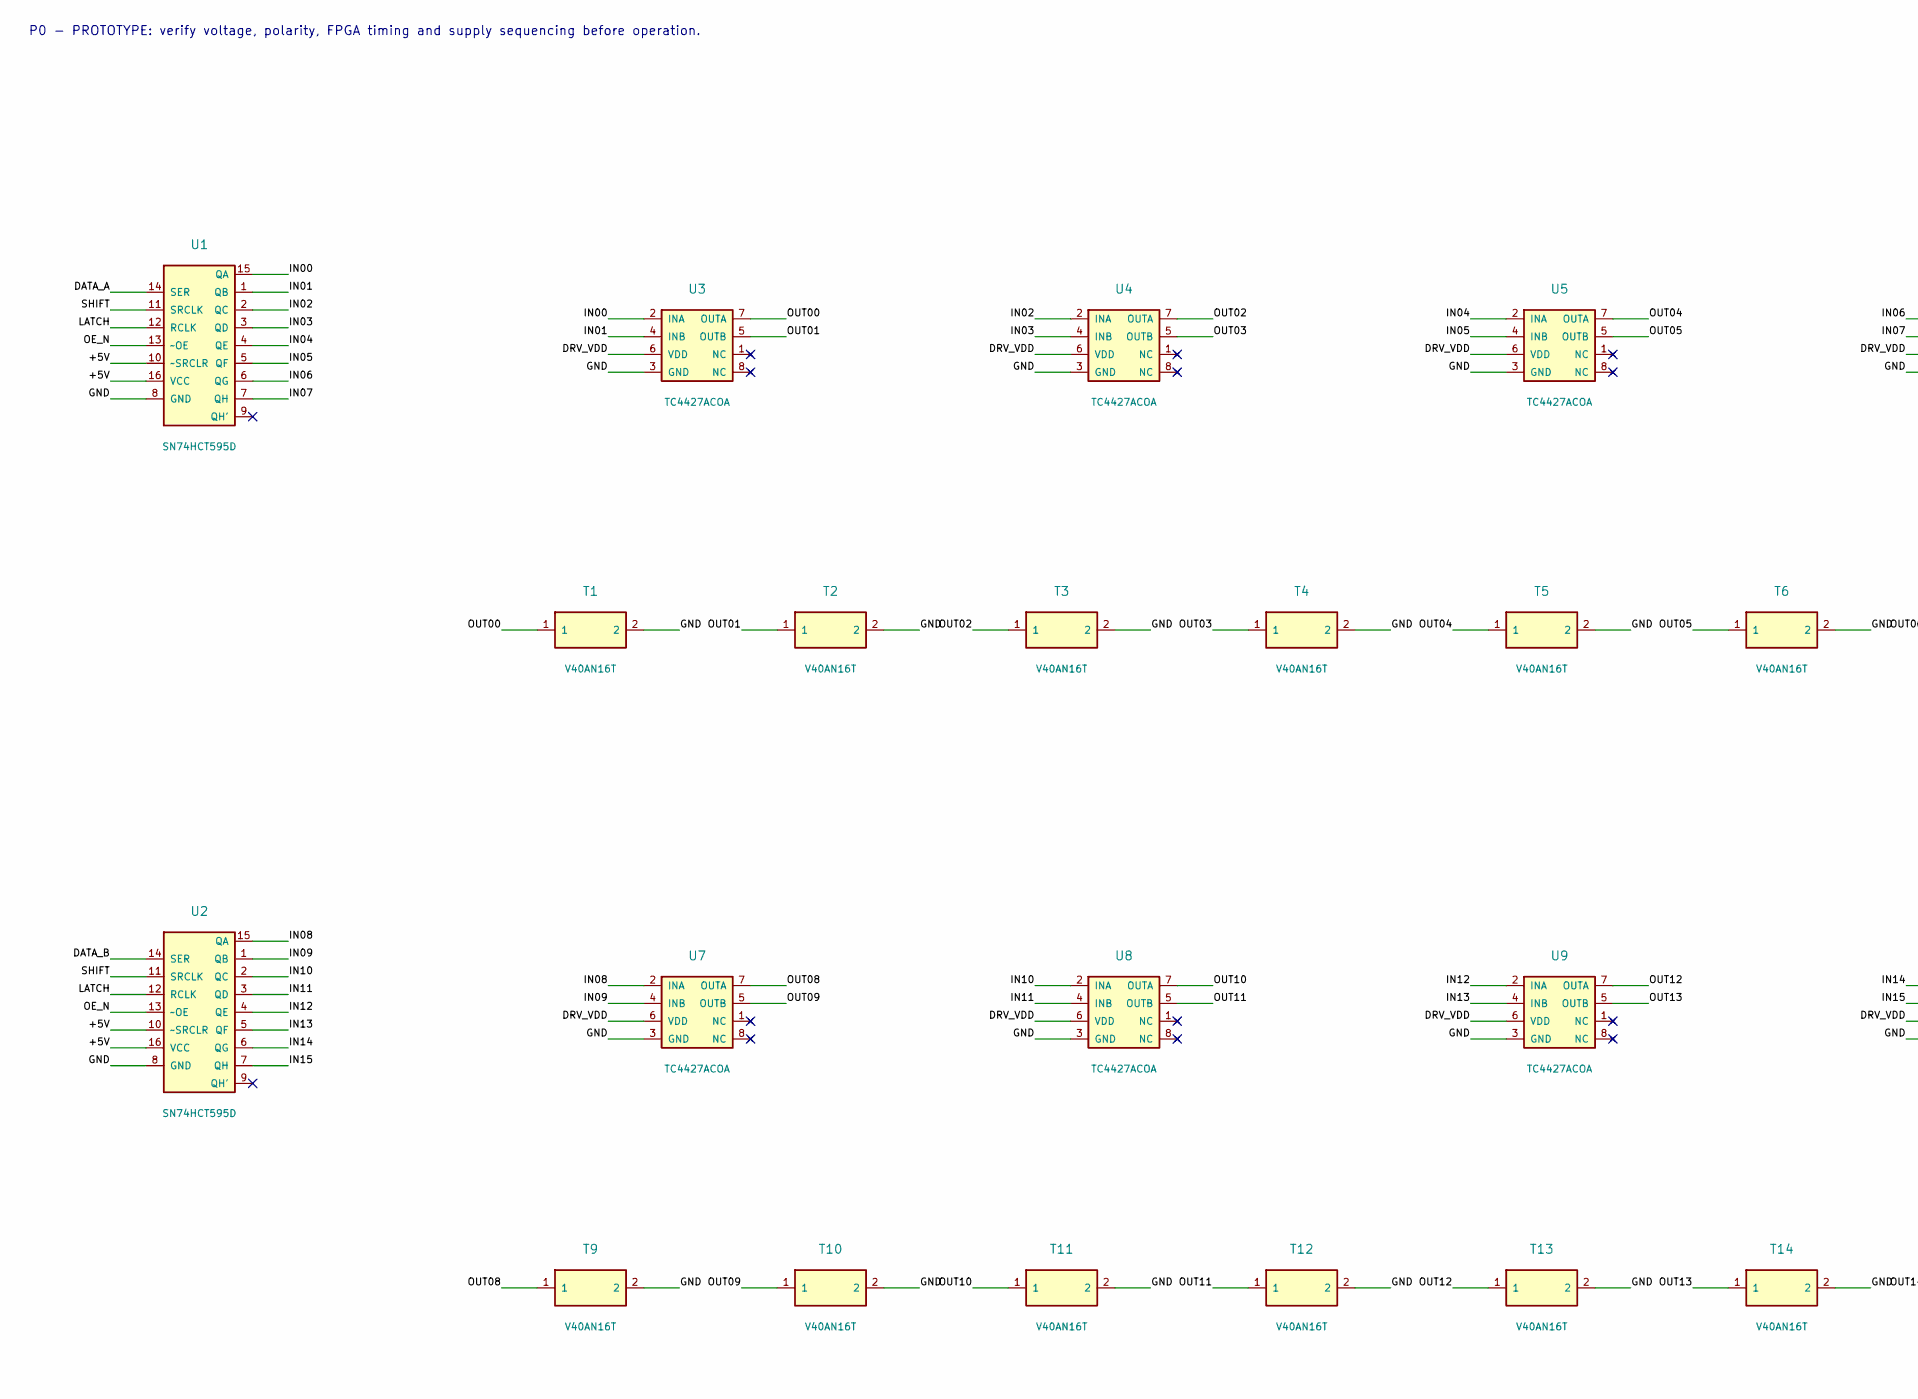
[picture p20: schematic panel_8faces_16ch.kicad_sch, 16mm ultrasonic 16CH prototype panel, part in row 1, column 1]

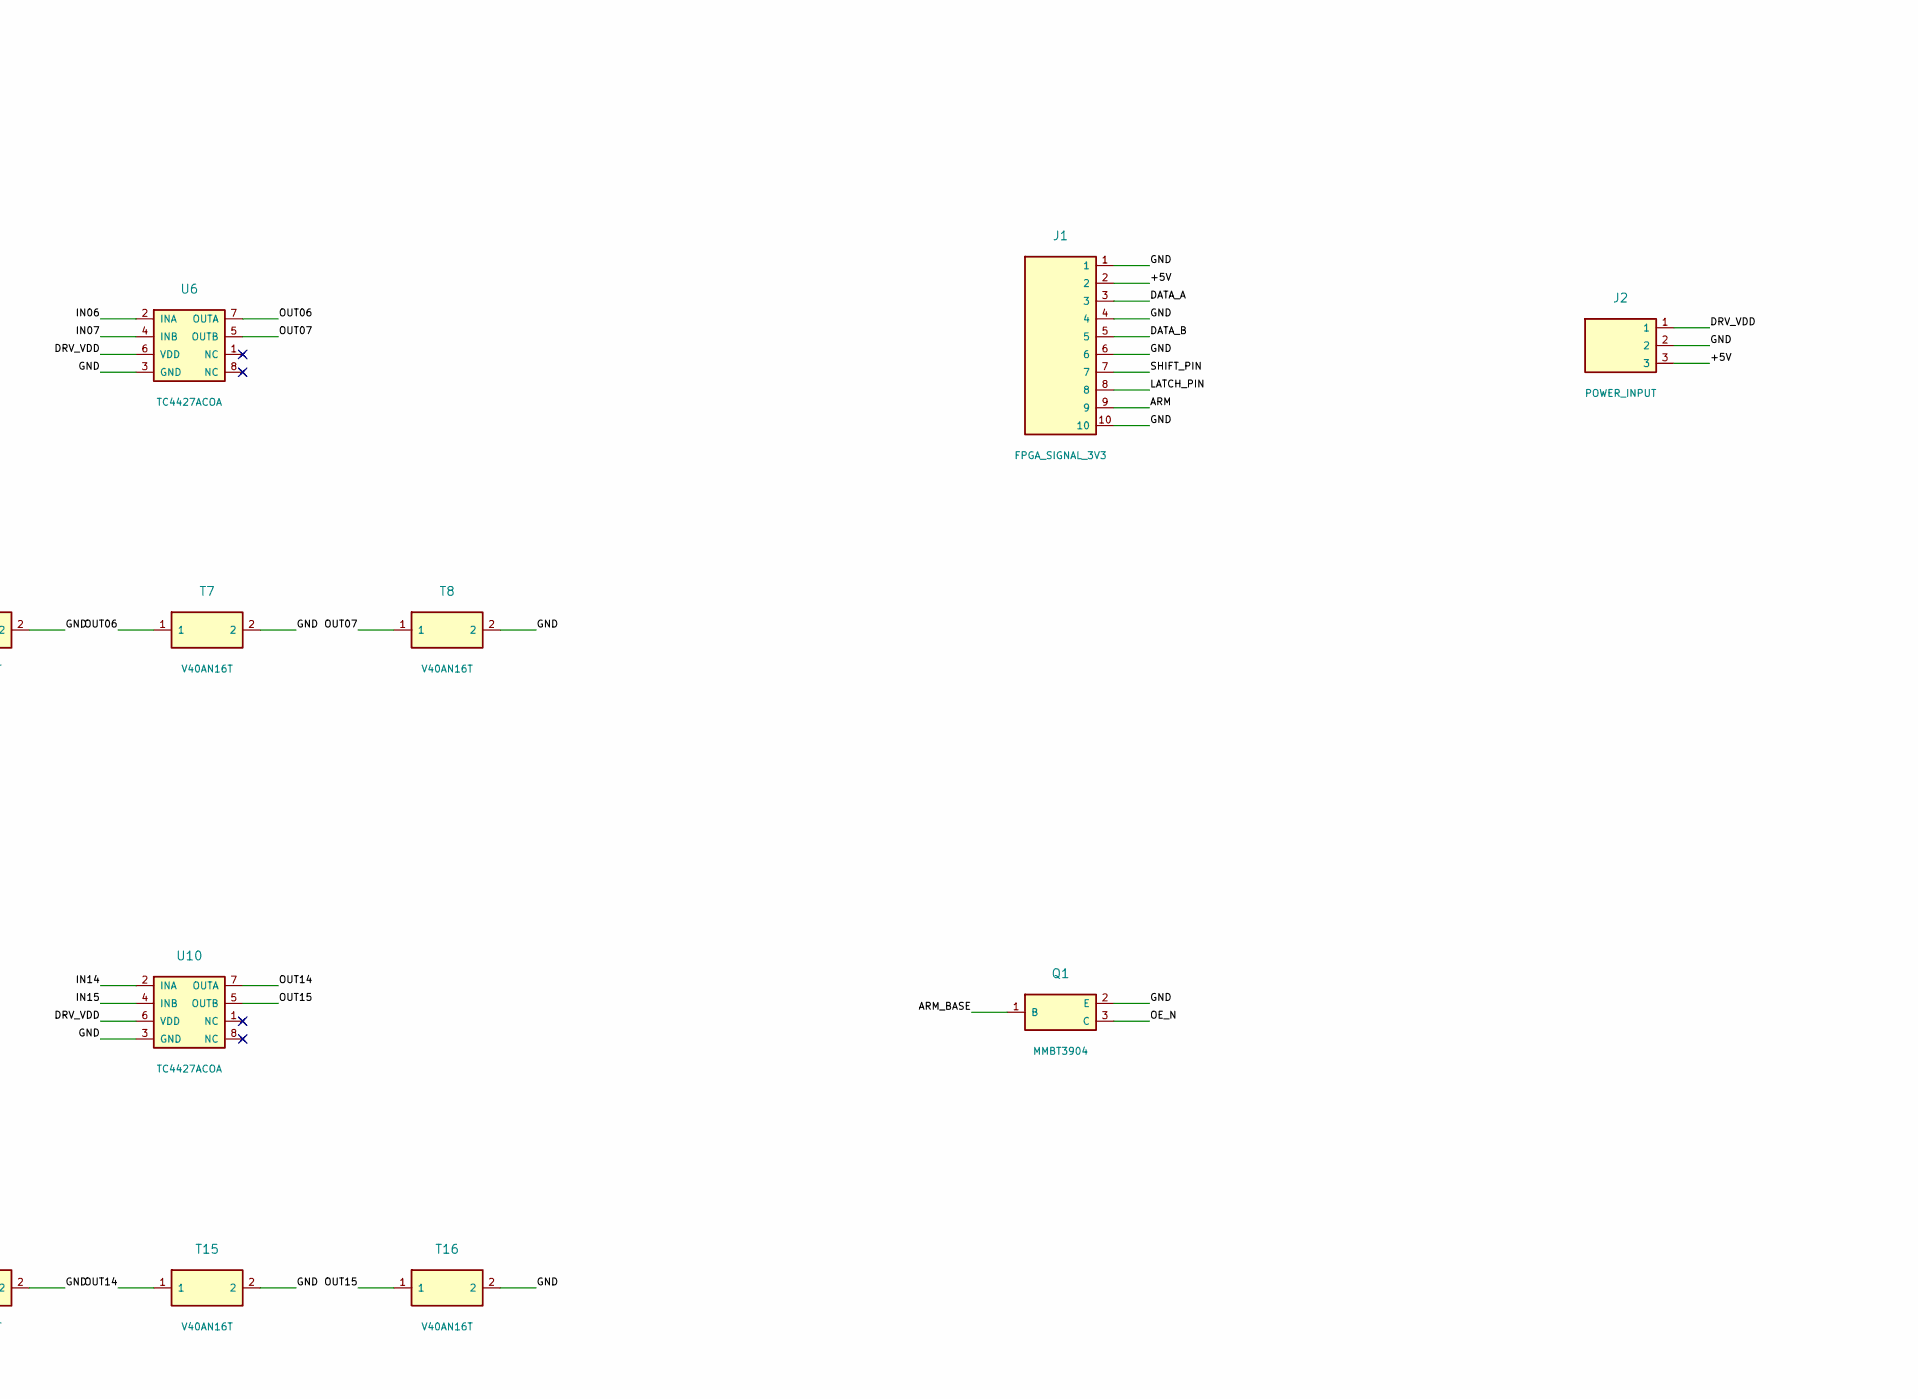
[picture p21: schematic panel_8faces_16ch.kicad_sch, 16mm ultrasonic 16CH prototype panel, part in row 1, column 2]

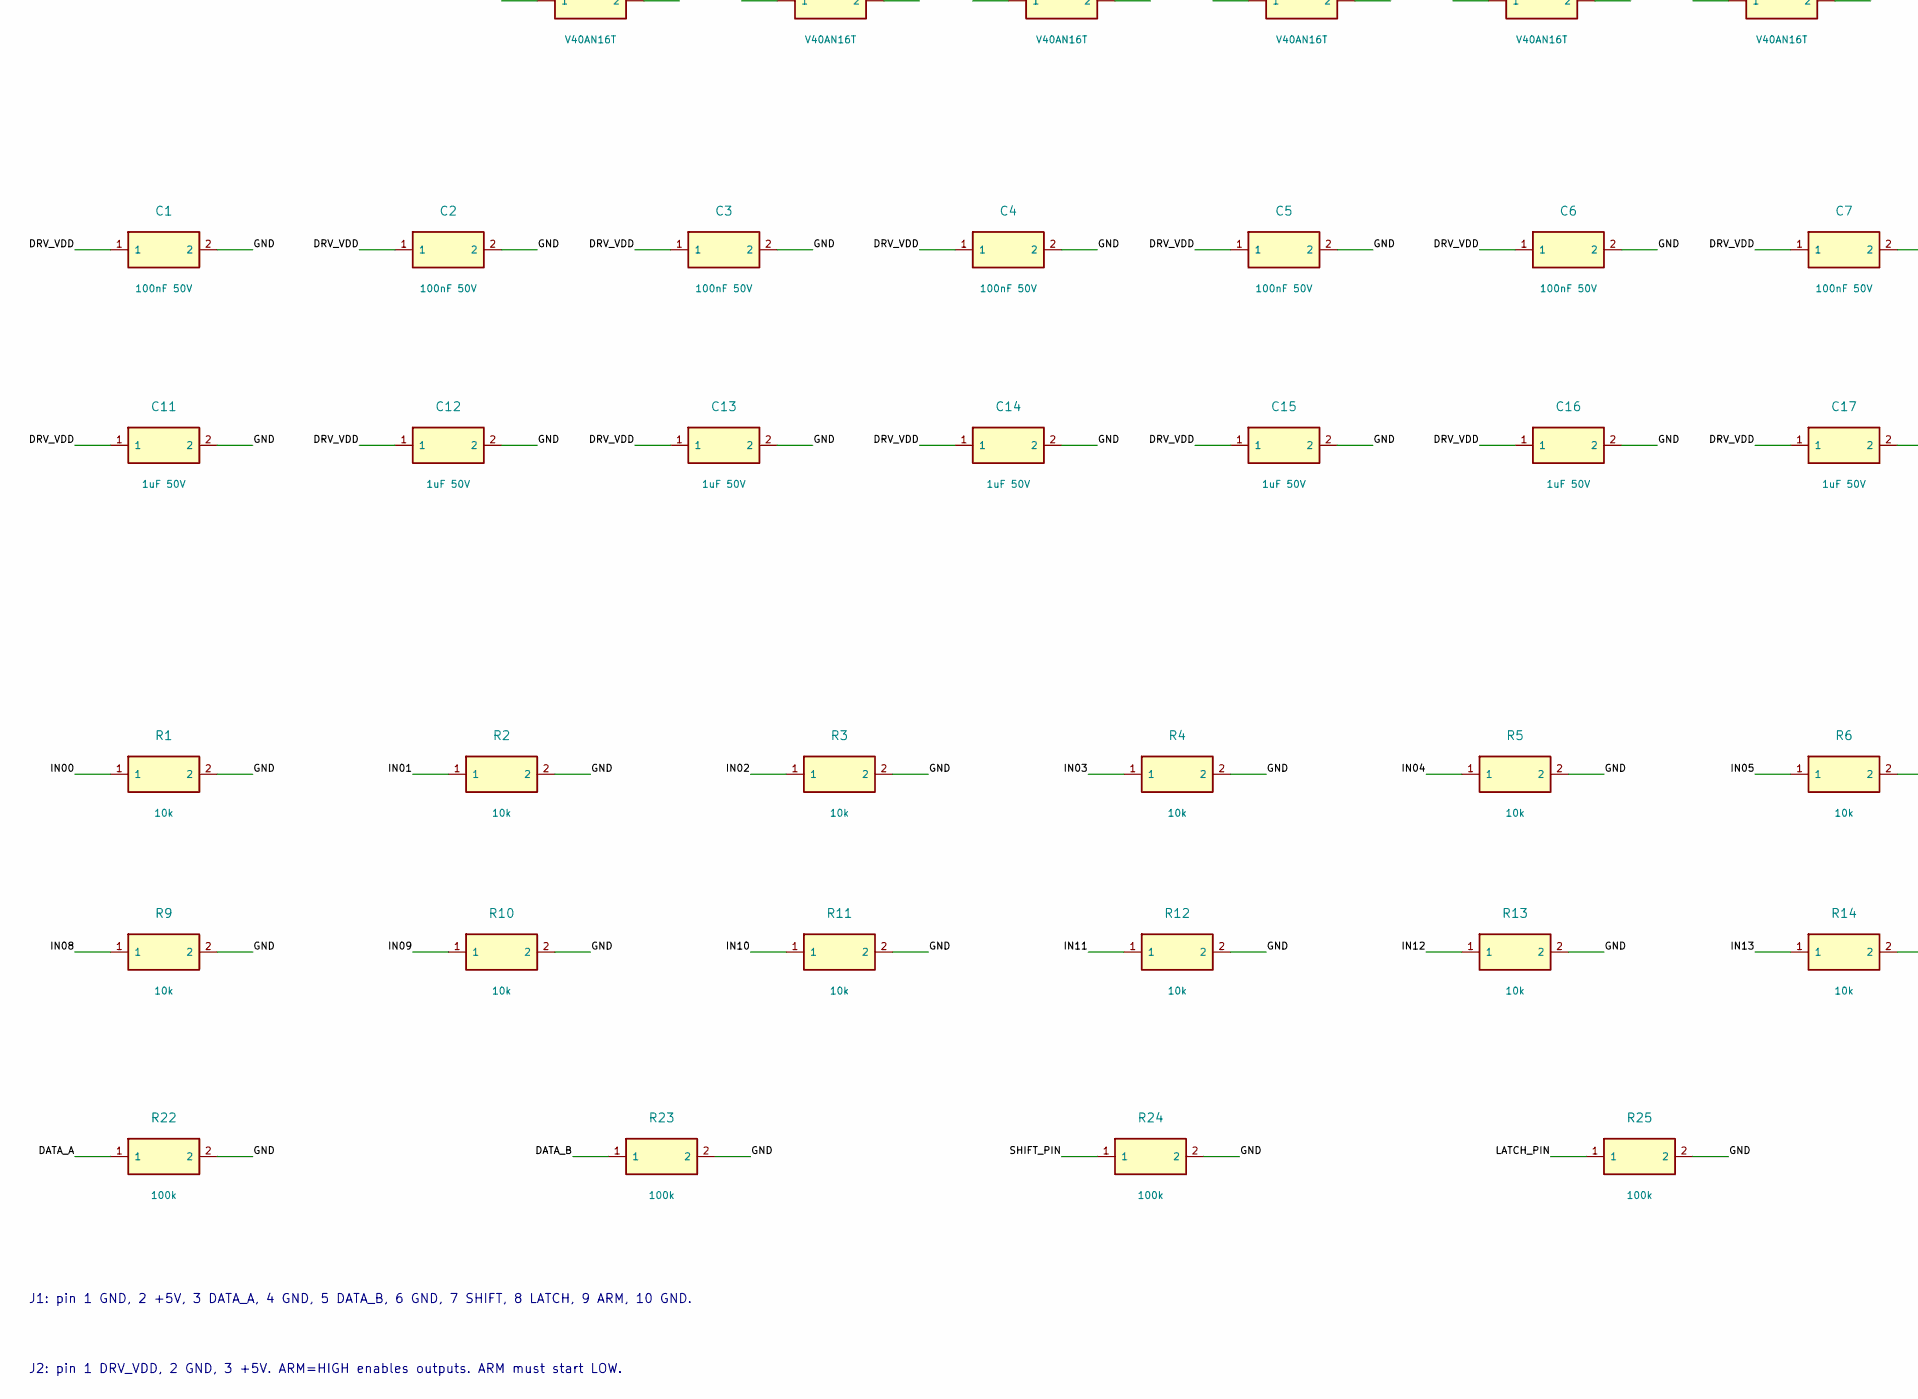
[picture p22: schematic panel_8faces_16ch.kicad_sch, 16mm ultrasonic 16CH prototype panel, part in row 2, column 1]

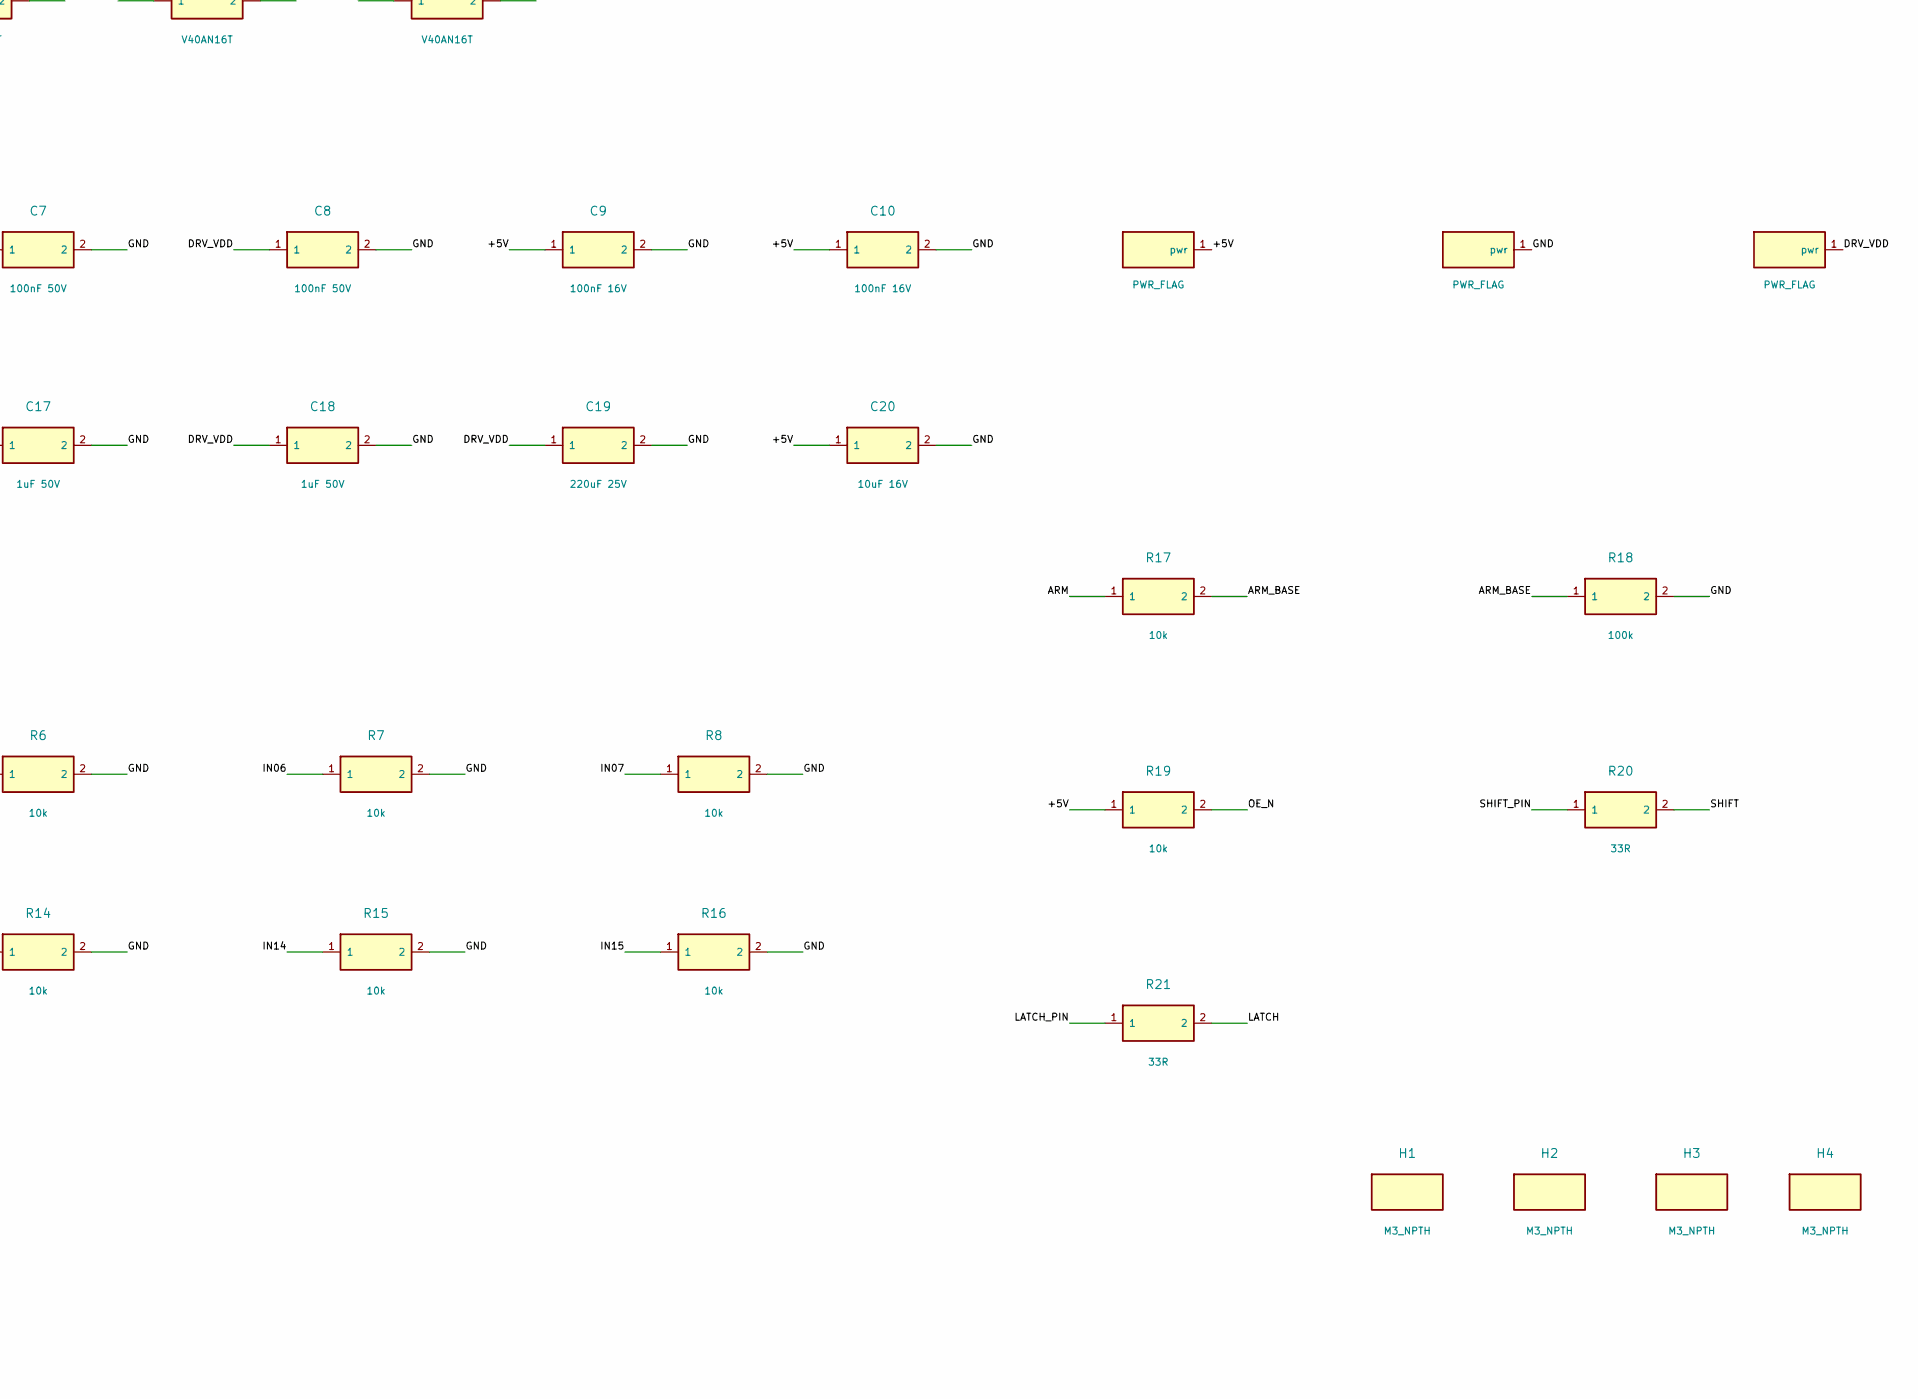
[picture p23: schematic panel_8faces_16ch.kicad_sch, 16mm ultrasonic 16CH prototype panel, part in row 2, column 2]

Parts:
C1, C2, C3, C4, C5, C6, C7, C8: 100nF 50V; C0805
C9, C10: 100nF 16V; C0805
C11, C12, C13, C14, C15, C16, C17, C18: 1uF 50V; C0805
C19: 220uF 25V; CP_Radial_D6.3_P2.5
C20: 10uF 16V; C0805
H1, H2, H3, H4: M3_NPTH; Mount_M3
J1: FPGA_SIGNAL_3V3; Header2x05
J2: POWER_INPUT; Header1x03
Q1: MMBT3904; SOT23
R1, R2, R3, R4, R5, R6, R7, R8, R9, R10, R11, R12, R13, R14, R15, R16, R17, R19: 10k; R0805
R18, R22, R23, R24, R25: 100k; R0805
R20, R21: 33R; R0805
T1, T2, T3, T4, T5, T6, T7, T8, T9, T10, T11, T12, T13, T14, T15, T16: V40AN16T; V40AN16T_P10
U1, U2: SN74HCT595D; SOIC16
U3, U4, U5, U6, U7, U8, U9, U10: TC4427ACOA; SOIC8

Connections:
/+5V: C9.1, C10.1, C20.1, J1.2, J2.3, R19.1, U1.10 (~SRCLR), U1.16 (VCC), U2.10 (~SRCLR), U2.16 (VCC)
/ARM: J1.9, R17.1
/ARM_BASE: Q1.1 (B), R17.2, R18.1
/DATA_A: J1.3, R22.1, U1.14 (SER)
/DATA_B: J1.5, R23.1, U2.14 (SER)
/DRV_VDD: C1.1, C2.1, C3.1, C4.1, C5.1, C6.1, C7.1, C8.1, C11.1, C12.1, C13.1, C14.1, C15.1, C16.1, C17.1, C18.1, C19.1, J2.1, U3.6 (VDD), U4.6 (VDD), U5.6 (VDD), U6.6 (VDD), U7.6 (VDD), U8.6 (VDD), U9.6 (VDD), U10.6 (VDD)
/GND: C1.2, C2.2, C3.2, C4.2, C5.2, C6.2, C7.2, C8.2, C9.2, C10.2, C11.2, C12.2, C13.2, C14.2, C15.2, C16.2, C17.2, C18.2, C19.2, C20.2, J1.1, J1.4, J1.6, J1.10, J2.2, Q1.2 (E), R1.2, R2.2, R3.2, R4.2, R5.2, R6.2, R7.2, R8.2, R9.2, R10.2, R11.2, R12.2, R13.2, R14.2, R15.2, R16.2, R18.2, R22.2, R23.2, R24.2, R25.2, T1.2, T2.2, T3.2, T4.2, T5.2, T6.2, T7.2, T8.2, T9.2, T10.2, T11.2, T12.2, T13.2, T14.2, T15.2, T16.2, U1.8 (GND), U2.8 (GND), U3.3 (GND), U4.3 (GND), U5.3 (GND), U6.3 (GND), U7.3 (GND), U8.3 (GND), U9.3 (GND), U10.3 (GND)
/IN00: R1.1, U1.15 (QA), U3.2 (INA)
/IN01: R2.1, U1.1 (QB), U3.4 (INB)
/IN02: R3.1, U1.2 (QC), U4.2 (INA)
/IN03: R4.1, U1.3 (QD), U4.4 (INB)
/IN04: R5.1, U1.4 (QE), U5.2 (INA)
/IN05: R6.1, U1.5 (QF), U5.4 (INB)
/IN06: R7.1, U1.6 (QG), U6.2 (INA)
/IN07: R8.1, U1.7 (QH), U6.4 (INB)
/IN08: R9.1, U2.15 (QA), U7.2 (INA)
/IN09: R10.1, U2.1 (QB), U7.4 (INB)
/IN10: R11.1, U2.2 (QC), U8.2 (INA)
/IN11: R12.1, U2.3 (QD), U8.4 (INB)
/IN12: R13.1, U2.4 (QE), U9.2 (INA)
/IN13: R14.1, U2.5 (QF), U9.4 (INB)
/IN14: R15.1, U2.6 (QG), U10.2 (INA)
/IN15: R16.1, U2.7 (QH), U10.4 (INB)
/LATCH: R21.2, U1.12 (RCLK), U2.12 (RCLK)
/LATCH_PIN: J1.8, R21.1, R25.1
/OE_N: Q1.3 (C), R19.2, U1.13 (~OE), U2.13 (~OE)
/OUT00: T1.1, U3.7 (OUTA)
/OUT01: T2.1, U3.5 (OUTB)
/OUT02: T3.1, U4.7 (OUTA)
/OUT03: T4.1, U4.5 (OUTB)
/OUT04: T5.1, U5.7 (OUTA)
/OUT05: T6.1, U5.5 (OUTB)
/OUT06: T7.1, U6.7 (OUTA)
/OUT07: T8.1, U6.5 (OUTB)
/OUT08: T9.1, U7.7 (OUTA)
/OUT09: T10.1, U7.5 (OUTB)
/OUT10: T11.1, U8.7 (OUTA)
/OUT11: T12.1, U8.5 (OUTB)
/OUT12: T13.1, U9.7 (OUTA)
/OUT13: T14.1, U9.5 (OUTB)
/OUT14: T15.1, U10.7 (OUTA)
/OUT15: T16.1, U10.5 (OUTB)
/SHIFT: R20.2, U1.11 (SRCLK), U2.11 (SRCLK)
/SHIFT_PIN: J1.7, R20.1, R24.1

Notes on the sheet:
P0 - PROTOTYPE: verify voltage, polarity, FPGA timing and supply sequencing before operation.
J1: pin 1 GND, 2 +5V, 3 DATA_A, 4 GND, 5 DATA_B, 6 GND, 7 SHIFT, 8 LATCH, 9 ARM, 10 GND.
J2: pin 1 DRV_VDD, 2 GND, 3 +5V. ARM=HIGH enables outputs. ARM must start LOW.

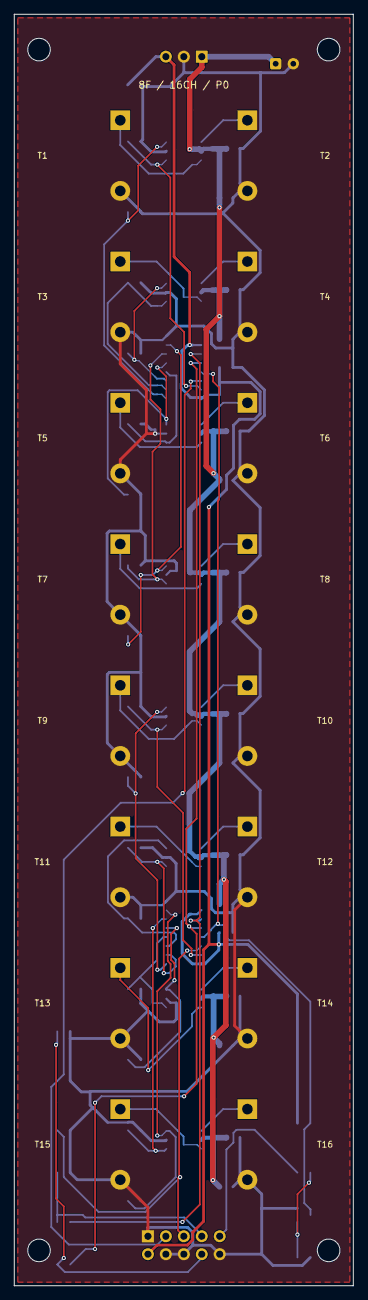
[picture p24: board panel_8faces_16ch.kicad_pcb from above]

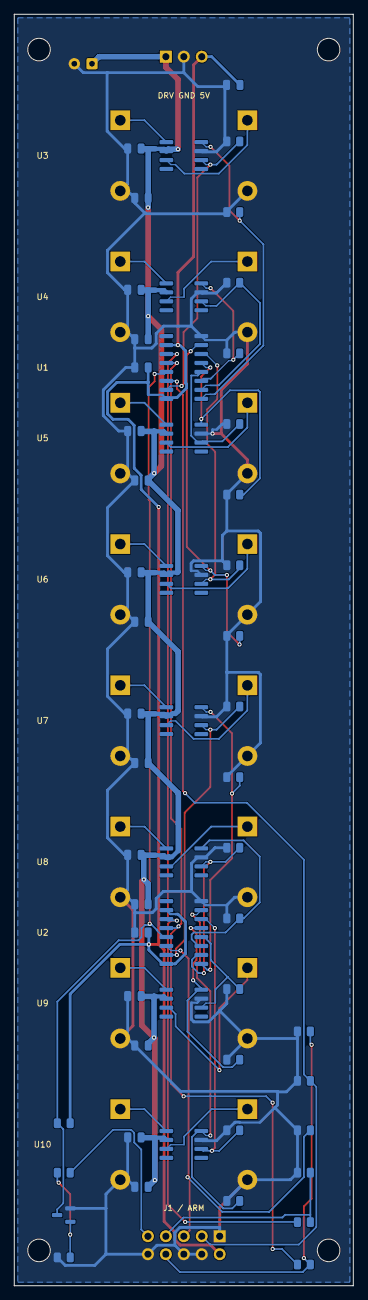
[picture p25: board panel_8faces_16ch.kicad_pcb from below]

Board: 2 copper layers, 48.0 x 180.0 mm, 78 parts (58 on the bottom side), 44 nets.

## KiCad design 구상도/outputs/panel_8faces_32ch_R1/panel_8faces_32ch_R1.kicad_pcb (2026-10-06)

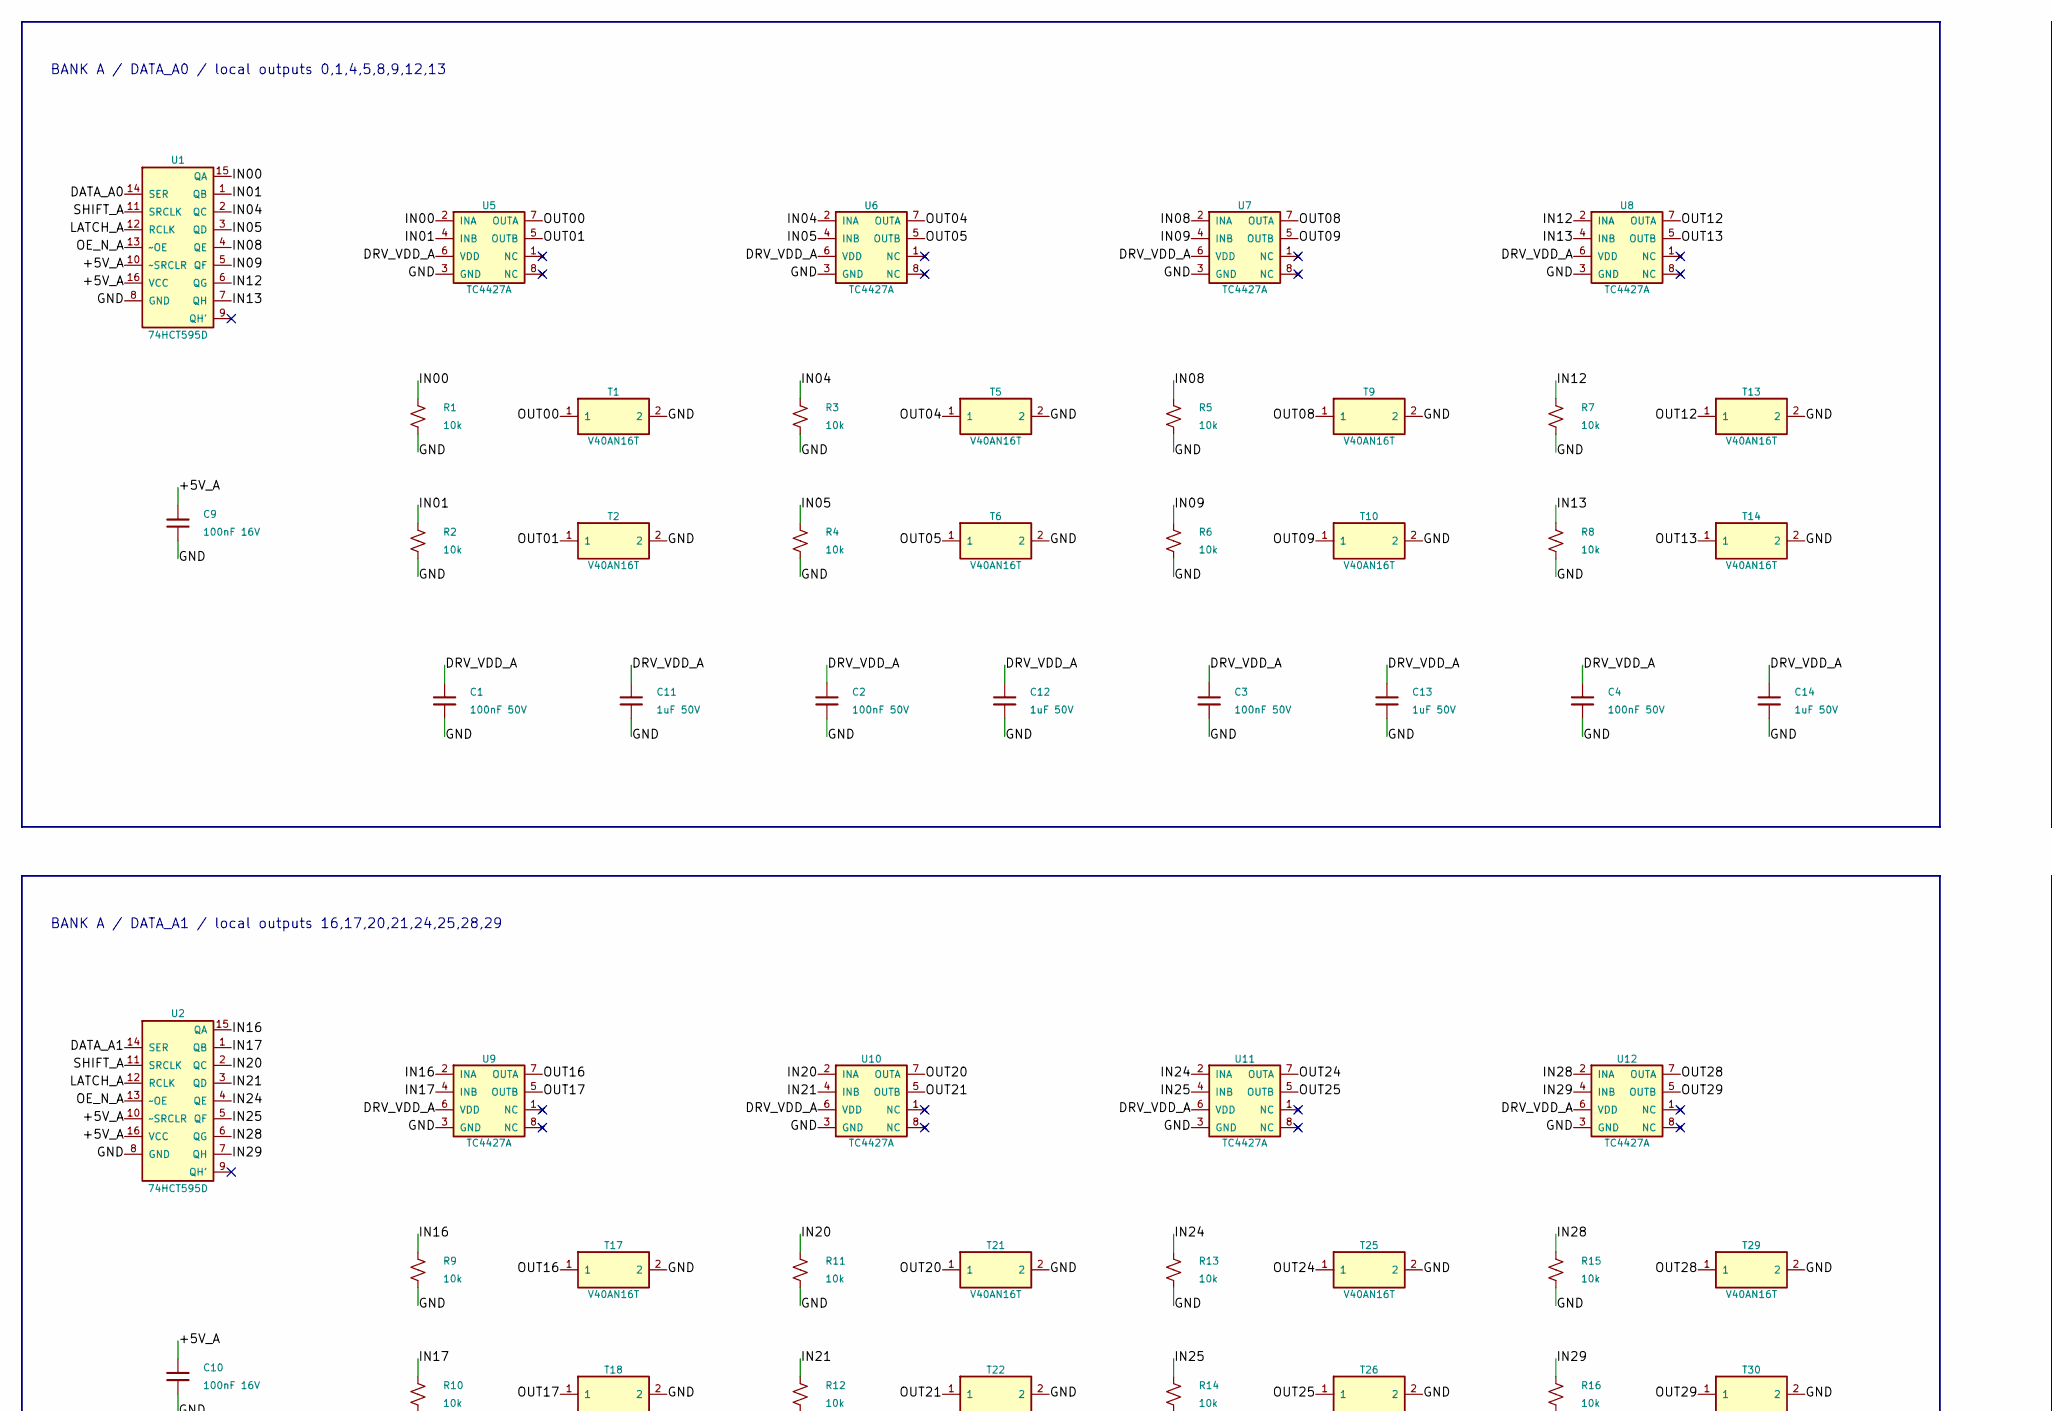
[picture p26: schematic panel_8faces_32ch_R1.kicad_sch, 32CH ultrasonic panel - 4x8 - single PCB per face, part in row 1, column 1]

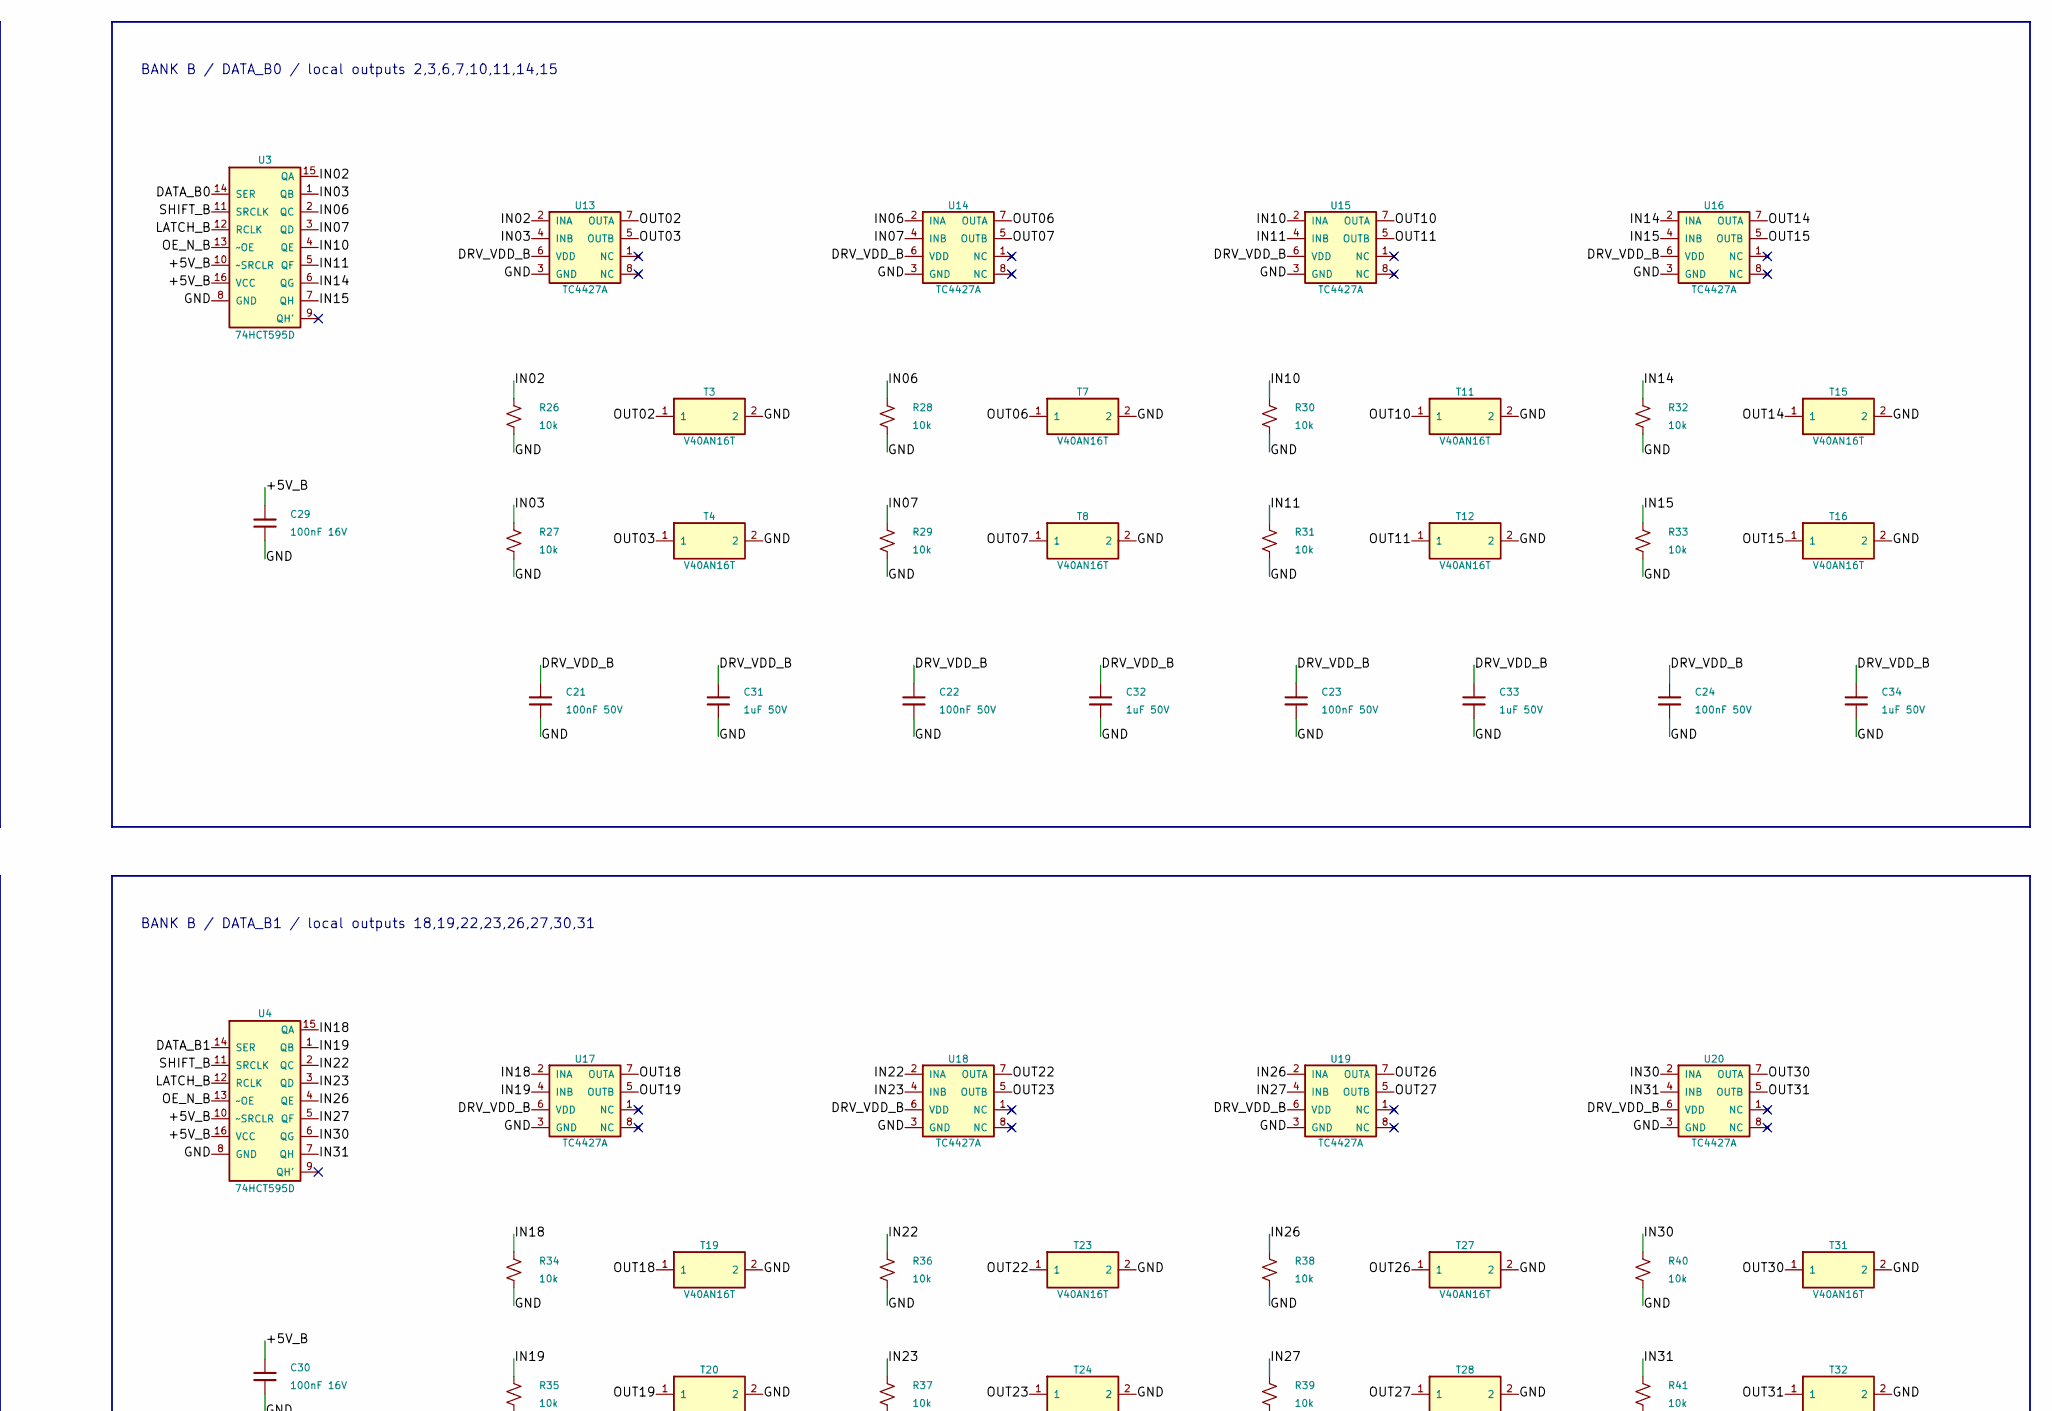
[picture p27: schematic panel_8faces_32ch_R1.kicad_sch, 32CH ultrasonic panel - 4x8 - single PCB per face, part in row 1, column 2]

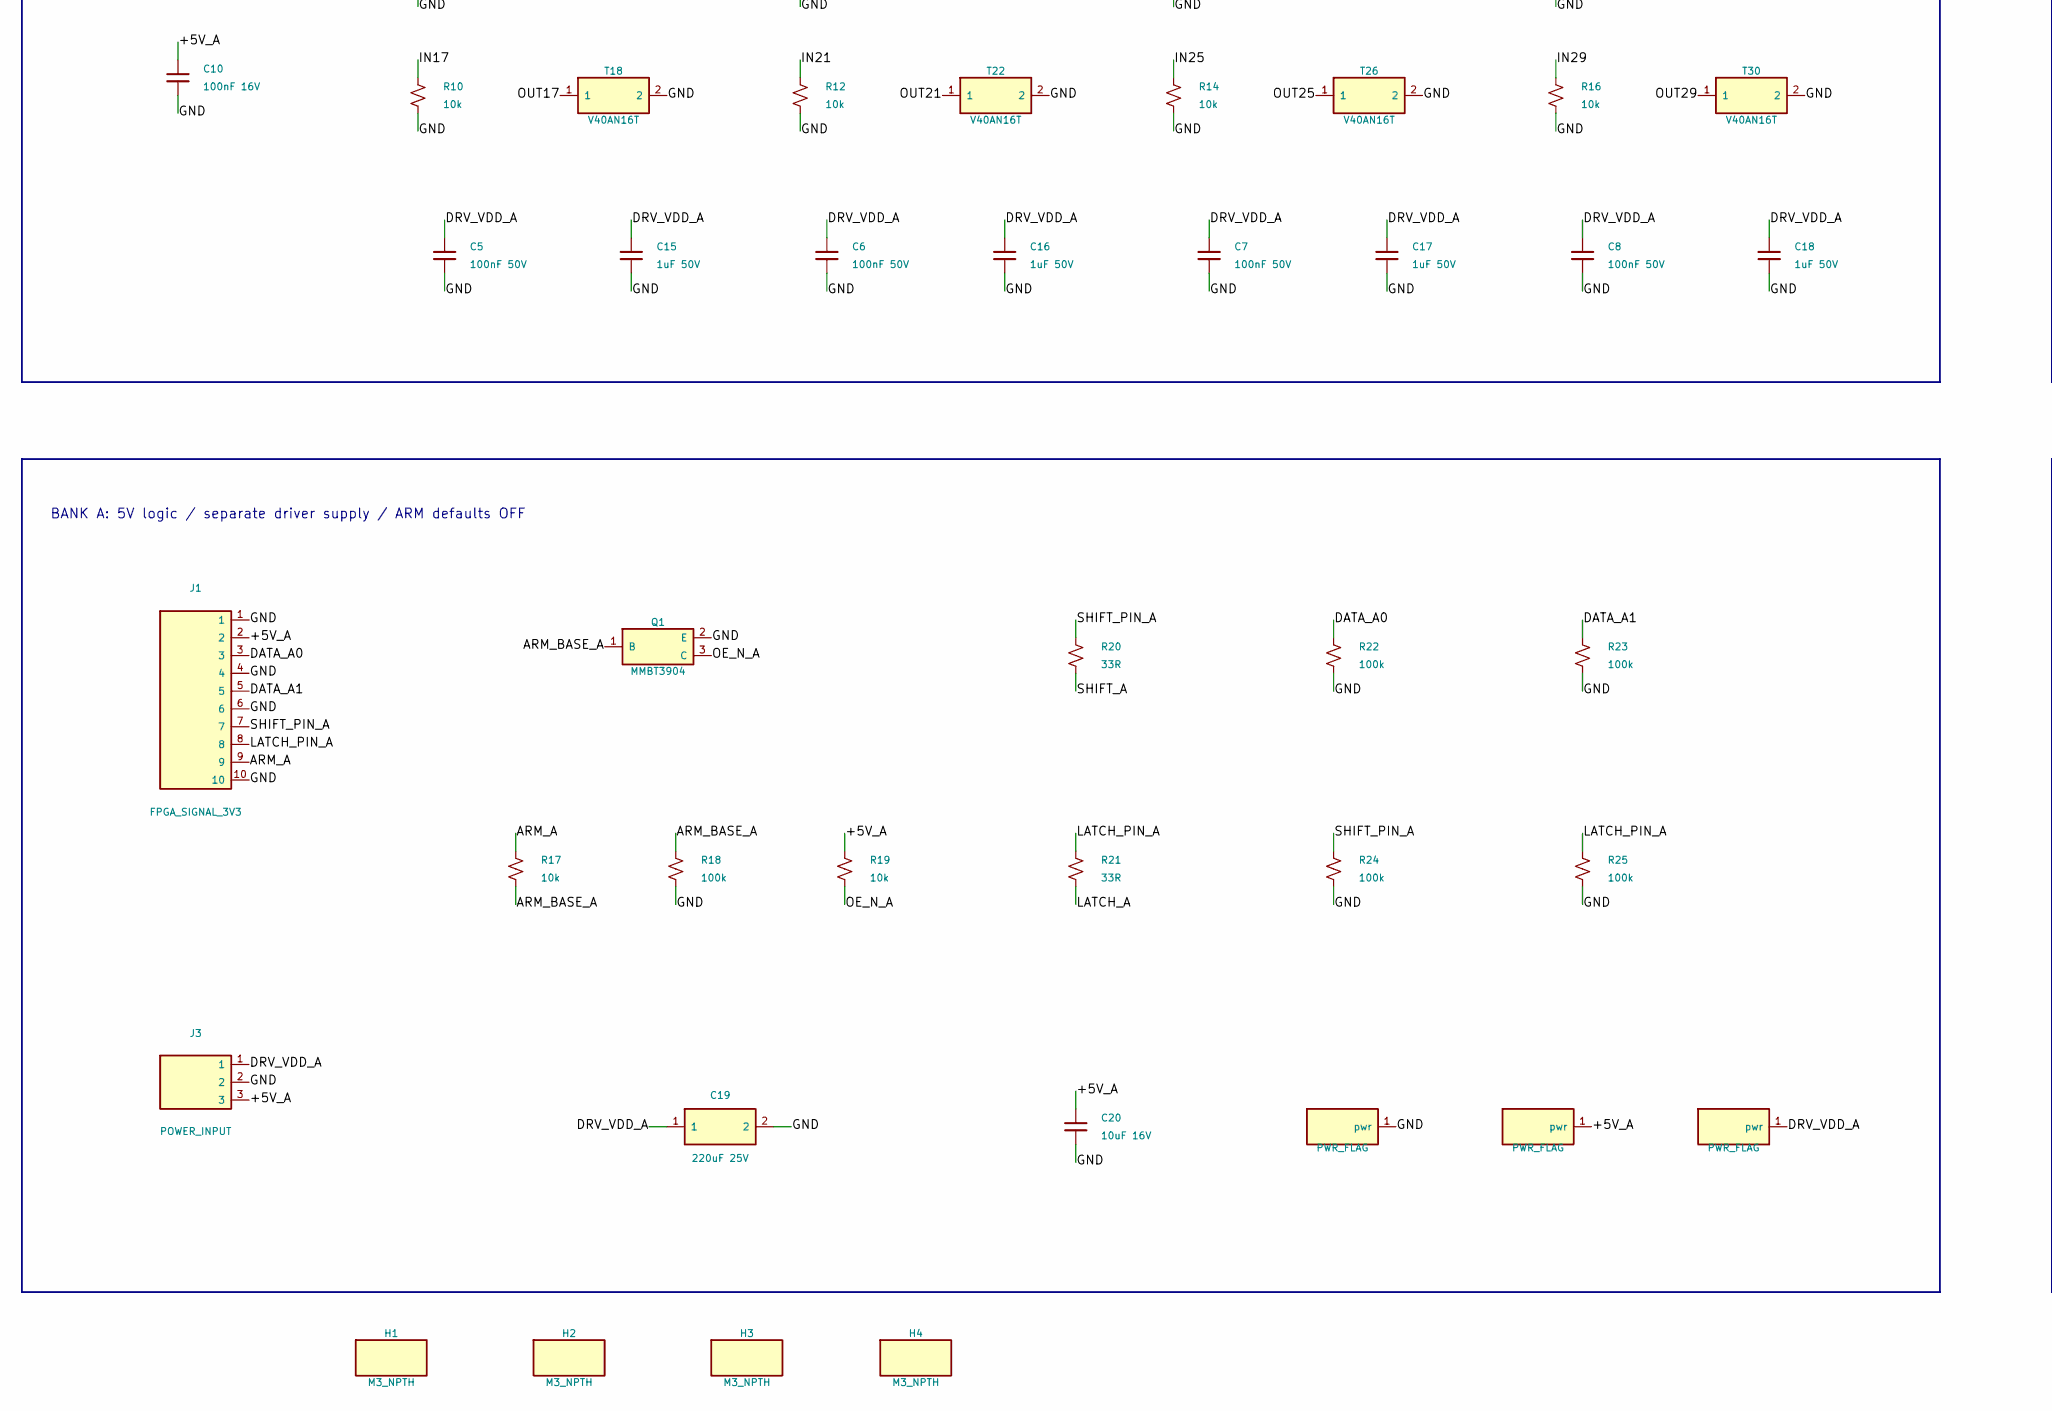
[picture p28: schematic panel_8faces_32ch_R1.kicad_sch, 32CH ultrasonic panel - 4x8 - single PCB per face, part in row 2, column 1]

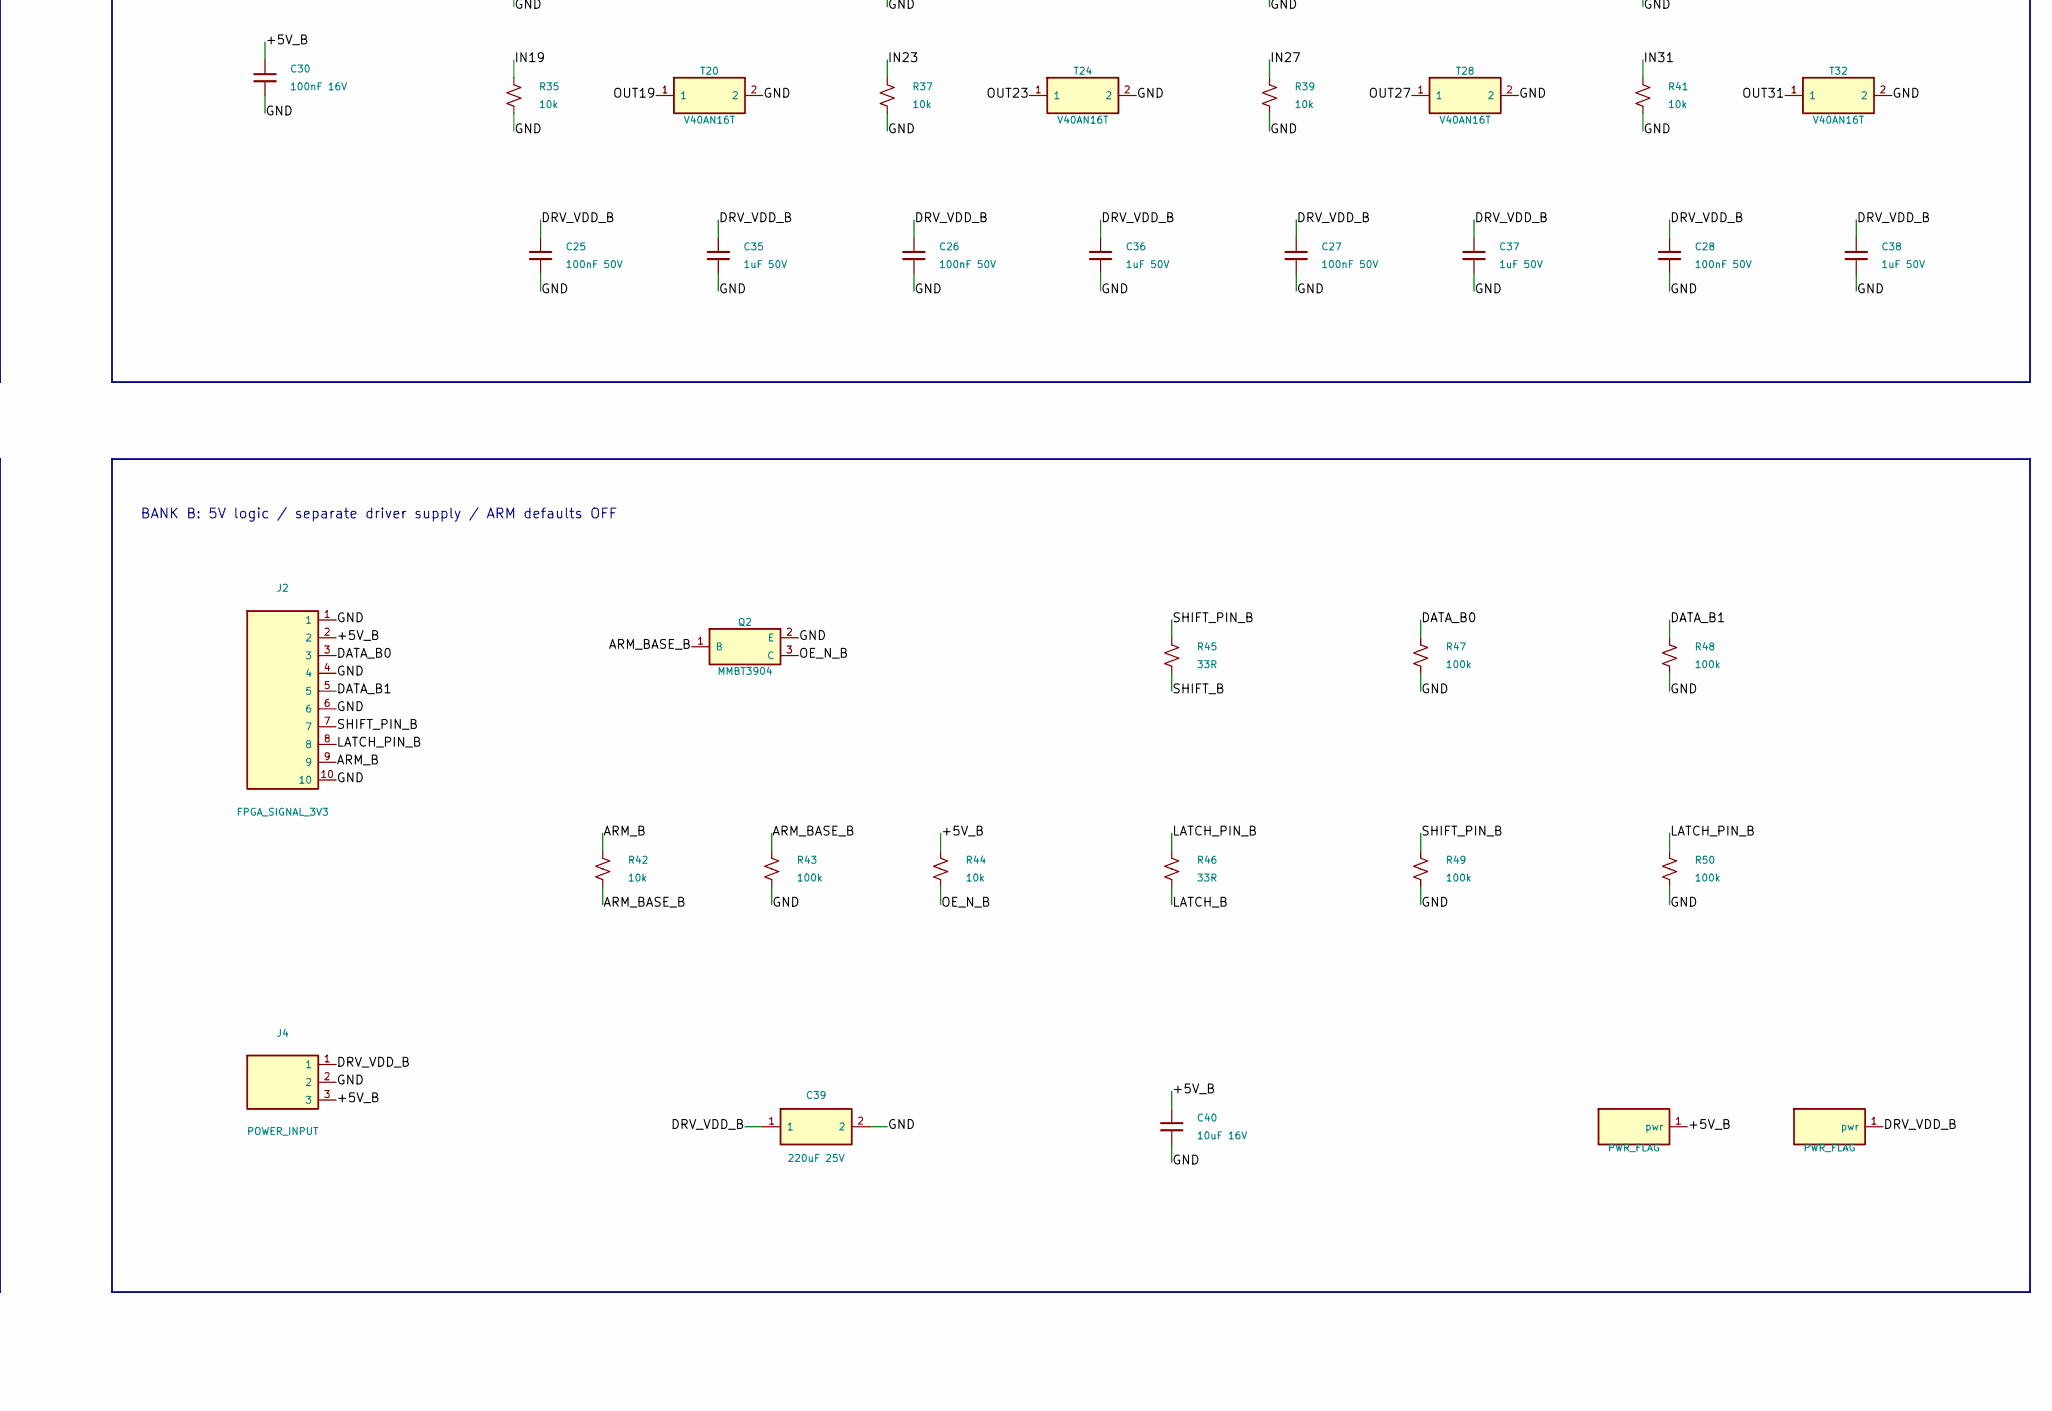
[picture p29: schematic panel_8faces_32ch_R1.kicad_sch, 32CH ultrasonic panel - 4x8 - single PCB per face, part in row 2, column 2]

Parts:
C1, C2, C3, C4, C5, C6, C7, C8, C21, C22, C23, C24, C25, C26, C27, C28: 100nF 50V; C0805; MPN CC0805KRX7R9BB104
C9, C10, C29, C30: 100nF 16V; C0805; MPN CC0805KRX7R9BB104
C11, C12, C13, C14, C15, C16, C17, C18, C31, C32, C33, C34, C35, C36, C37, C38: 1uF 50V; C0805; MPN TCC0805X7R105K500DT
C19, C39: 220uF 25V; CP_Radial_D6.3_P2.5; MPN 25YXJ220M6.3X11
C20, C40: 10uF 16V; C0805; MPN GRM21BR61E106KA73L
H1, H2, H3, H4: M3_NPTH; Mount_M3
J1, J2: FPGA_SIGNAL_3V3; Header2x05
J3, J4: POWER_INPUT; Header1x03
Q1, Q2: MMBT3904; SOT23; MPN MMBT3904,215
R1, R2, R3, R4, R5, R6, R7, R8, R9, R10, R11, R12, R13, R14, R15, R16, R17, R19, R26, R27, R28, R29, R30, R31, R32, R33, R34, R35, R36, R37, R38, R39, R40, R41, R42, R44: 10k; R0805; MPN RC0805FR-0710KL
R18, R22, R23, R24, R25, R43, R47, R48, R49, R50: 100k; R0805; MPN RC0805FR-07100KL
R20, R21, R45, R46: 33R; R0805; MPN RC0805FR-0733RL
T1, T2, T3, T4, T5, T6, T7, T8, T9, T10, T11, T12, T13, T14, T15, T16, T17, T18, T19, T20, T21, T22, T23, T24, T25, T26, T27, T28, T29, T30, T31, T32: V40AN16T; V40AN16T_P10
U1, U2, U3, U4: 74HCT595D; SOIC16; MPN 74HCT595D,118
U5, U6, U7, U8, U9, U10, U11, U12, U13, U14, U15, U16, U17, U18, U19, U20: TC4427A; SOIC8; MPN TC4427ACOA713

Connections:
/+5V_A: C9.1, C10.1, C20.1, J1.2, J3.3, R19.1, U1.10 (~SRCLR), U1.16 (VCC), U2.10 (~SRCLR), U2.16 (VCC)
/+5V_B: C29.1, C30.1, C40.1, J2.2, J4.3, R44.1, U3.10 (~SRCLR), U3.16 (VCC), U4.10 (~SRCLR), U4.16 (VCC)
/ARM_A: J1.9, R17.1
/ARM_B: J2.9, R42.1
/ARM_BASE_A: Q1.1 (B), R17.2, R18.1
/ARM_BASE_B: Q2.1 (B), R42.2, R43.1
/DATA_A0: J1.3, R22.1, U1.14 (SER)
/DATA_A1: J1.5, R23.1, U2.14 (SER)
/DATA_B0: J2.3, R47.1, U3.14 (SER)
/DATA_B1: J2.5, R48.1, U4.14 (SER)
/DRV_VDD_A: C1.1, C2.1, C3.1, C4.1, C5.1, C6.1, C7.1, C8.1, C11.1, C12.1, C13.1, C14.1, C15.1, C16.1, C17.1, C18.1, C19.1, J3.1, U5.6 (VDD), U6.6 (VDD), U7.6 (VDD), U8.6 (VDD), U9.6 (VDD), U10.6 (VDD), U11.6 (VDD), U12.6 (VDD)
/DRV_VDD_B: C21.1, C22.1, C23.1, C24.1, C25.1, C26.1, C27.1, C28.1, C31.1, C32.1, C33.1, C34.1, C35.1, C36.1, C37.1, C38.1, C39.1, J4.1, U13.6 (VDD), U14.6 (VDD), U15.6 (VDD), U16.6 (VDD), U17.6 (VDD), U18.6 (VDD), U19.6 (VDD), U20.6 (VDD)
/GND: C1.2, C2.2, C3.2, C4.2, C5.2, C6.2, C7.2, C8.2, C9.2, C10.2, C11.2, C12.2, C13.2, C14.2, C15.2, C16.2, C17.2, C18.2, C19.2, C20.2, C21.2, C22.2, C23.2, C24.2, C25.2, C26.2, C27.2, C28.2, C29.2, C30.2, C31.2, C32.2, C33.2, C34.2, C35.2, C36.2, C37.2, C38.2, C39.2, C40.2, J1.1, J1.4, J1.6, J1.10, J2.1, J2.4, J2.6, J2.10, J3.2, J4.2, Q1.2 (E), Q2.2 (E), R1.2, R2.2, R3.2, R4.2, R5.2, R6.2, R7.2, R8.2, R9.2, R10.2, R11.2, R12.2, R13.2, R14.2, R15.2, R16.2, R18.2, R22.2, R23.2, R24.2, R25.2, R26.2, R27.2, R28.2, R29.2, R30.2, R31.2, R32.2, R33.2, R34.2, R35.2, R36.2, R37.2, R38.2, R39.2, R40.2, R41.2, R43.2, R47.2, R48.2, R49.2, R50.2, T1.2, T2.2, T3.2, T4.2, T5.2, T6.2, T7.2, T8.2, T9.2, T10.2, T11.2, T12.2, T13.2, T14.2, T15.2, T16.2, T17.2, T18.2, T19.2, T20.2, T21.2, T22.2, T23.2, T24.2, T25.2, T26.2, T27.2, T28.2, T29.2, T30.2, T31.2, T32.2, U1.8 (GND), U2.8 (GND), U3.8 (GND), U4.8 (GND), U5.3 (GND), U6.3 (GND), U7.3 (GND), U8.3 (GND), U9.3 (GND), U10.3 (GND), U11.3 (GND), U12.3 (GND), U13.3 (GND), U14.3 (GND), U15.3 (GND), U16.3 (GND), U17.3 (GND), U18.3 (GND), U19.3 (GND), U20.3 (GND)
/IN00: R1.1, U1.15 (QA), U5.2 (INA)
/IN01: R2.1, U1.1 (QB), U5.4 (INB)
/IN02: R26.1, U3.15 (QA), U13.2 (INA)
/IN03: R27.1, U3.1 (QB), U13.4 (INB)
/IN04: R3.1, U1.2 (QC), U6.2 (INA)
/IN05: R4.1, U1.3 (QD), U6.4 (INB)
/IN06: R28.1, U3.2 (QC), U14.2 (INA)
/IN07: R29.1, U3.3 (QD), U14.4 (INB)
/IN08: R5.1, U1.4 (QE), U7.2 (INA)
/IN09: R6.1, U1.5 (QF), U7.4 (INB)
/IN10: R30.1, U3.4 (QE), U15.2 (INA)
/IN11: R31.1, U3.5 (QF), U15.4 (INB)
/IN12: R7.1, U1.6 (QG), U8.2 (INA)
/IN13: R8.1, U1.7 (QH), U8.4 (INB)
/IN14: R32.1, U3.6 (QG), U16.2 (INA)
/IN15: R33.1, U3.7 (QH), U16.4 (INB)
/IN16: R9.1, U2.15 (QA), U9.2 (INA)
/IN17: R10.1, U2.1 (QB), U9.4 (INB)
/IN18: R34.1, U4.15 (QA), U17.2 (INA)
/IN19: R35.1, U4.1 (QB), U17.4 (INB)
/IN20: R11.1, U2.2 (QC), U10.2 (INA)
/IN21: R12.1, U2.3 (QD), U10.4 (INB)
/IN22: R36.1, U4.2 (QC), U18.2 (INA)
/IN23: R37.1, U4.3 (QD), U18.4 (INB)
/IN24: R13.1, U2.4 (QE), U11.2 (INA)
/IN25: R14.1, U2.5 (QF), U11.4 (INB)
/IN26: R38.1, U4.4 (QE), U19.2 (INA)
/IN27: R39.1, U4.5 (QF), U19.4 (INB)
/IN28: R15.1, U2.6 (QG), U12.2 (INA)
/IN29: R16.1, U2.7 (QH), U12.4 (INB)
/IN30: R40.1, U4.6 (QG), U20.2 (INA)
/IN31: R41.1, U4.7 (QH), U20.4 (INB)
/LATCH_A: R21.2, U1.12 (RCLK), U2.12 (RCLK)
/LATCH_B: R46.2, U3.12 (RCLK), U4.12 (RCLK)
/LATCH_PIN_A: J1.8, R21.1, R25.1
/LATCH_PIN_B: J2.8, R46.1, R50.1
/OE_N_A: Q1.3 (C), R19.2, U1.13 (~OE), U2.13 (~OE)
/OE_N_B: Q2.3 (C), R44.2, U3.13 (~OE), U4.13 (~OE)
/OUT00: T1.1, U5.7 (OUTA)
/OUT01: T2.1, U5.5 (OUTB)
/OUT02: T3.1, U13.7 (OUTA)
/OUT03: T4.1, U13.5 (OUTB)
/OUT04: T5.1, U6.7 (OUTA)
/OUT05: T6.1, U6.5 (OUTB)
/OUT06: T7.1, U14.7 (OUTA)
/OUT07: T8.1, U14.5 (OUTB)
/OUT08: T9.1, U7.7 (OUTA)
/OUT09: T10.1, U7.5 (OUTB)
/OUT10: T11.1, U15.7 (OUTA)
/OUT11: T12.1, U15.5 (OUTB)
/OUT12: T13.1, U8.7 (OUTA)
/OUT13: T14.1, U8.5 (OUTB)
/OUT14: T15.1, U16.7 (OUTA)
/OUT15: T16.1, U16.5 (OUTB)
/OUT16: T17.1, U9.7 (OUTA)
/OUT17: T18.1, U9.5 (OUTB)
/OUT18: T19.1, U17.7 (OUTA)
/OUT19: T20.1, U17.5 (OUTB)
/OUT20: T21.1, U10.7 (OUTA)
/OUT21: T22.1, U10.5 (OUTB)
/OUT22: T23.1, U18.7 (OUTA)
/OUT23: T24.1, U18.5 (OUTB)
/OUT24: T25.1, U11.7 (OUTA)
/OUT25: T26.1, U11.5 (OUTB)
/OUT26: T27.1, U19.7 (OUTA)
/OUT27: T28.1, U19.5 (OUTB)
/OUT28: T29.1, U12.7 (OUTA)
/OUT29: T30.1, U12.5 (OUTB)
/OUT30: T31.1, U20.7 (OUTA)
/OUT31: T32.1, U20.5 (OUTB)
/SHIFT_A: R20.2, U1.11 (SRCLK), U2.11 (SRCLK)
/SHIFT_B: R45.2, U3.11 (SRCLK), U4.11 (SRCLK)
/SHIFT_PIN_A: J1.7, R20.1, R24.1
/SHIFT_PIN_B: J2.7, R45.1, R49.1

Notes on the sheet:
BANK A / DATA_A0 / local outputs 0,1,4,5,8,9,12,13
BANK A / DATA_A1 / local outputs 16,17,20,21,24,25,28,29
BANK B / DATA_B0 / local outputs 2,3,6,7,10,11,14,15
BANK B / DATA_B1 / local outputs 18,19,22,23,26,27,30,31
BANK A: 5V logic / separate driver supply / ARM defaults OFF
BANK B: 5V logic / separate driver supply / ARM defaults OFF

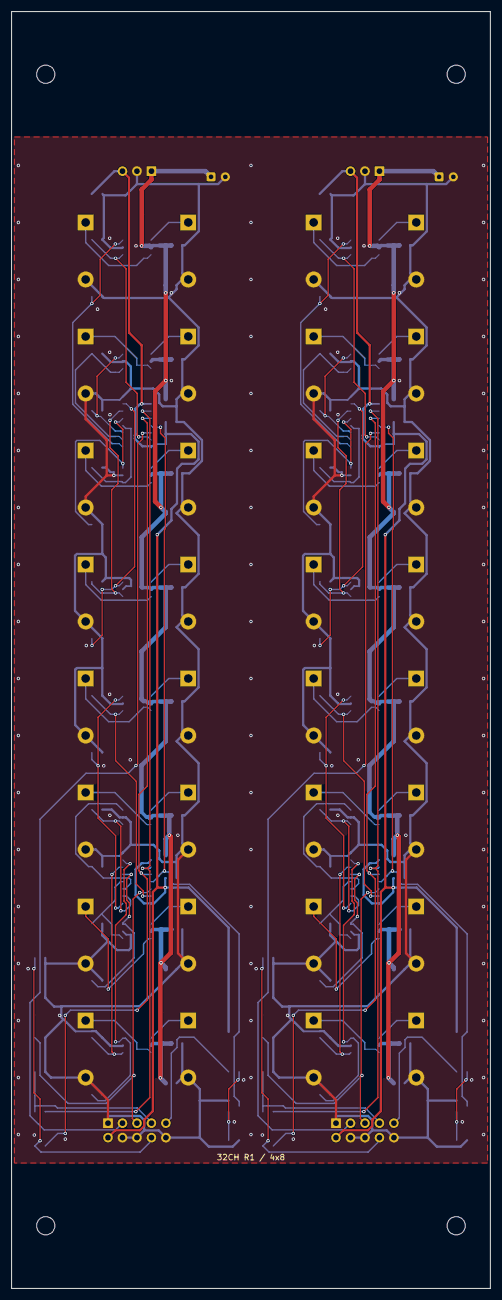
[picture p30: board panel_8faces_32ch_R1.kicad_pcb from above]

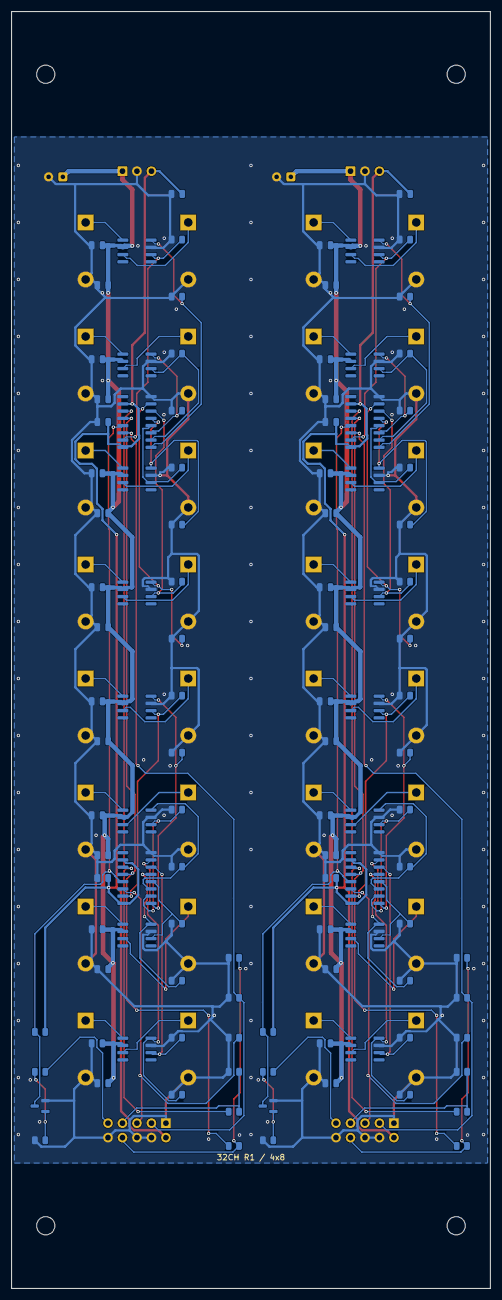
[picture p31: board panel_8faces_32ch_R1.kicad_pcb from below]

Board: 2 copper layers, 84.0 x 224.0 mm, 152 parts (116 on the bottom side), 87 nets.

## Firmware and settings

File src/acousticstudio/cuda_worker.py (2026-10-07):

"""Fresh interpreter for optional CUDA packages; no widgets, VTK or serial access."""
from pathlib import Path
import sys


def serve(target):
    sys.path.insert(0, str(Path(__file__).resolve().parents[1]))
    sys.path.insert(0, str(Path(target).resolve()))
    from acousticstudio.cuda_protocol import read_message, write_message
    wire = sys.stdout.buffer
    sys.stdout = sys.stderr  # Library diagnostics cannot corrupt the binary pipe.
    torch = None
    while True:
        try:
            operation, arguments = read_message(sys.stdin.buffer)
        except EOFError:
            return
        try:
            if torch is None:
                import torch
            if operation == 'probe':
                available = bool(torch.cuda.is_available())
                if available:
                    # Also check a real complex128 kernel, beyond package/device presence.
                    value = torch.ones((1, 1), dtype=torch.complex128, device='cuda')
                    value = value @ value
                    torch.cuda.synchronize()
                result = dict(torch_version=str(torch.__version__), torch_cuda_build=torch.version.cuda,
                              cuda_available=available, cuda_device=torch.cuda.get_device_name() if available else None,
                              cuda_error=None if available else '별도 PyTorch 런타임이 CUDA 장치를 사용할 수 없습니다.',
                              torch_file=str(Path(torch.__file__).resolve()))
            elif operation == 'matvec':
                matrix, weights = arguments
                result = (torch.as_tensor(matrix, dtype=torch.complex128, device='cuda') @
                          torch.as_tensor(weights, dtype=torch.complex128, device='cuda')).cpu().numpy()
            elif operation in ('phases', 'field_slice'):
                from acousticstudio import sonic_wrapper
                if not sonic_wrapper._has_cuda:
                    raise RuntimeError('CUDA 계산 프로세스가 GPU를 사용할 수 없습니다.')
                function = (sonic_wrapper.calculate_phases_gpu if operation == 'phases'
                            else sonic_wrapper.calculate_field_slice_gpu)
                result = function(*arguments)
            else:
                raise ValueError('지원하지 않는 CUDA 계산 요청입니다.')
            response = dict(ok=True, value=result)
        except Exception as exc:
            response = dict(ok=False, error=str(exc))
        write_message(wire, response)


if __name__ == '__main__':
    serve(sys.argv[1])

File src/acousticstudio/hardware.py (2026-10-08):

# -*- coding: utf-8 -*-
"""Hardware controller module for AcousticStudio.

Manages serial port communication with ultrasonic transducer boards.
Communicates state changes through Qt signals rather than direct UI access.
"""

from dataclasses import dataclass
from math import floor, isfinite, pi
from typing import Iterable
from time import monotonic, perf_counter
from math import ceil

import serial
import serial.tools.list_ports
from PySide6.QtCore import QObject, QTimer, QThread, Signal
from acousticstudio.calibration import validate_active, validate_mapping


@dataclass(frozen=True)
class BoardProfile:
    """A documented on-wire protocol for a supported phased-array board.

    ``channel_count`` is intentionally strict for real board profiles: silently
    sending a partial 256-channel frame can leave a previously driven channel
    active.  The legacy profile is retained for small experimental arrays.
    """

    key: str
    label: str
    channel_count: int | None
    baud_rate: int
    transport: str
    source: str
    off_code: int | None = None
    rounding: str = 'ties_even'


BOARD_PROFILES = {
    "legacy_phase32": BoardProfile(
        "legacy_phase32", "Legacy Phase32 (0xFE … 0xFD)", None, 115200,
        "phase32_frame", "AcousticStudio existing packet format",
    ),
    "ultraino_simplefpga_256": BoardProfile(
        "ultraino_simplefpga_256", "Ultraino SimpleFPGA 256", 256, 230400,
        "phase32_frame", "Ultraino SimpleFPGA.java", 32, 'half_up',
    ),
    "sonicsurface_fpga_256": BoardProfile(
        "sonicsurface_fpga_256", "SonicSurface FPGA 256 (direct)", 256, 230400,
        "phase32_frame", "SonicSurface TestHoloConnection4.ino", 32, 'half_up',
    ),
    "sonicsurface_fpga_two_board": BoardProfile(
        "sonicsurface_fpga_two_board", "SonicSurface FPGA 256 (board tags)", 256, 230400,
        "sonicsurface_two_board", "SonicSurface CommandSenderESP32.ino", 32, 'half_up',
    ),
    "sonicsurface_esp32_command": BoardProfile(
        "sonicsurface_esp32_command", "SonicSurface ESP32 CommandSender", 256, 230400,
        "sonicsurface_ascii", "SonicSurface CommandSenderESP32.ino", 32, 'half_up',
    ),
}


def phases_to_steps(phases_radians: Iterable[float], steps: int = 32, rounding: str = 'ties_even') -> list[int]:
    """Quantise radians using an explicit client rounding policy, wrapping at 2π.

    Firmware uses 0–31 while 32 is its *off* value.  Modulo before rounding
    avoids incorrectly turning a phase near 2π into the off code.
    """
    if type(steps) is not int or not 1 <= steps <= 255 or rounding not in ('ties_even', 'half_up'):
        raise ValueError('위상 분할 수 또는 반올림 방식이 잘못되었습니다.')
    values: list[int] = []
    for phase in phases_radians:
        value = float(phase)
        if not isfinite(value):
            raise ValueError("위상 값에는 NaN 또는 무한대를 사용할 수 없습니다.")
        scaled = ((value % (2.0 * pi)) / (2.0 * pi)) * steps
        values.append((floor(scaled + .5) if rounding == 'half_up' else int(round(scaled))) % steps)
    return values


def encode_phase_frame(profile: BoardProfile, phases_radians: Iterable[float], active=None) -> bytes:
    """Encode one complete, committed phase frame for *profile*."""
    phase_steps = phases_to_steps(phases_radians, rounding=profile.rounding)
    if not phase_steps:
        raise ValueError("전송할 트랜스듀서 위상이 없습니다.")
    if profile.channel_count is not None and len(phase_steps) != profile.channel_count:
        raise ValueError(
            f"{profile.label} 프로파일은 정확히 {profile.channel_count}채널을 요구하지만 "
            f"현재 배열은 {len(phase_steps)}채널입니다."
        )

    if active is not None:
        enabled = validate_active(active, len(phase_steps))
        if not all(enabled) and profile.off_code is None:
            raise ValueError(f'{profile.label} 프로파일은 OFF를 지원하지 않습니다.')
        phase_steps = [step if enabled[index] else profile.off_code for index, step in enumerate(phase_steps)]
    return encode_steps(profile, phase_steps)


def encode_steps(profile, phase_steps):
    """Internal encoder for validated physical-order Phase32/OFF values."""
    payload = bytes(phase_steps)
    if profile.transport == "phase32_frame":
        return bytes((0xFE,)) + payload + bytes((0xFD,))
    if profile.transport == "sonicsurface_two_board":
        # The ESP32 reference firmware forwards each 128-channel half with
        # board-enable tags 0xC0 and 0xC1, then commits with 0xFD.
        return bytes((0xFE, 0xC0)) + payload[:128] + bytes((0xC1,)) + payload[128:] + bytes((0xFD,))
    if profile.transport == "sonicsurface_ascii":
        # CommandSenderESP32 parses values only when it encounters a separator;
        # retain the final comma so the 256th value is committed as well.
        return b"phases=" + b",".join(str(step).encode("ascii") for step in phase_steps) + b",\n"
    raise ValueError(f"지원하지 않는 전송 형식: {profile.transport}")
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

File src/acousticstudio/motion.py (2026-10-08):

"""World-space slice manipulation, in millimetres; no Qt or actor state."""
import numpy as np

PLANE_AXES = {'xy': 2, 'xz': 1, 'yz': 0}


def ray_plane_intersection(origin, direction, plane, offset):
    origin, direction = np.asarray(origin, dtype=float), np.asarray(direction, dtype=float)
    if origin.shape != (3,) or direction.shape != (3,) or not np.isfinite([origin, direction]).all():
        raise ValueError('픽킹 광선은 유한한 XYZ 좌표여야 합니다.')
    if plane not in PLANE_AXES or not np.isfinite(offset):
        raise ValueError('단면과 위치가 잘못되었습니다.')
    axis = PLANE_AXES[plane]
    length = np.linalg.norm(direction)
    if length == 0 or abs(direction[axis]) <= 1e-10 * length:
        return None
    distance = (offset - origin[axis]) / direction[axis]
    if distance < 0:
        return None
    result = origin + distance * direction
    result[axis] = offset
    return result


def translated_points(points, destination):
    points, destination = np.asarray(points, dtype=float), np.asarray(destination, dtype=float)
    if points.ndim != 2 or points.shape[1] != 3 or not len(points) or destination.shape != (3,):
        raise ValueError('이동할 제어점과 XYZ 목적지가 필요합니다.')
    if not np.isfinite(points).all() or not np.isfinite(destination).all():
        raise ValueError('이동 좌표는 유한해야 합니다.')
    return points + destination - points.mean(axis=0)

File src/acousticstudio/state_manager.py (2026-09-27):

# -*- coding: utf-8 -*-
"""
Undo/Redo state management for Acoustic Control Studio.

Extracted from AcousticStudioMain.push_state / undo / redo methods.
Pure Python — no Qt dependency required.
"""

from __future__ import annotations


class StateManager:
    """Manages undo/redo state stacks.

    Stores snapshots of application state (as dicts) and provides
    push / undo / redo / clear operations with a configurable maximum
    stack depth.
    """

    def __init__(self, max_undo: int = 20):
        self.undo_stack: list[dict] = []
        self.redo_stack: list[dict] = []
        self._max_undo = max_undo

    # ------------------------------------------------------------------
    # Public API
    # ------------------------------------------------------------------

    def push(self, state: dict) -> None:
        """Push a new state snapshot.

        Only pushes if *state* differs from the most recent entry on the
        undo stack.  Clears the redo stack on every push.
        """
        # Only push if different from last state
        if not self.undo_stack or self.undo_stack[-1] != state:
            self.undo_stack.append(state)
            self.redo_stack.clear()

            # limit stack size
            if len(self.undo_stack) > self._max_undo:
                self.undo_stack.pop(0)

    def undo(self, current_state: dict) -> dict | None:
        """Return the previous state, or ``None`` if nothing to undo.

        *current_state* is the live application state at the moment the
        user requests an undo.  If it differs from the top of the undo
        stack it is pushed first so that no work is lost.
        """
        if len(self.undo_stack) < 1:
            return None

        # If the current live state differs from what's on top, capture it
        if self.undo_stack[-1] != current_state:
            self.undo_stack.append(current_state)
            self.redo_stack.clear()

        if len(self.undo_stack) > 1:
            current = self.undo_stack.pop()
            self.redo_stack.append(current)
            return self.undo_stack[-1]

        return None

    def redo(self) -> dict | None:
        """Return the next (redo) state, or ``None`` if nothing to redo."""
        if self.redo_stack:
            next_state = self.redo_stack.pop()
            self.undo_stack.append(next_state)
            return next_state
        return None

    def clear(self) -> None:
        """Discard all undo and redo history."""
        self.undo_stack.clear()
        self.redo_stack.clear()

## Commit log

2026-09-22 Fix: Replace vtkAxesTransformWidget with vtkBoxWidget2 for intuitive 3D gizmo translation
    [app.py]
2026-09-22 Fix: Replace vtkBoxWidget2 with Custom PyVista Gizmo (RGB spheres, hover, 1D lock)
    [app.py]
2026-09-22 Fix: Resolve UnboundLocalError and Gizmo click logic, scale down Gizmo size
    [app.py]
2026-09-22 Fix: Add Gizmo hover highlight and ensure Gizmo follows object during drag
    [app.py]
2026-09-22 Feat: Add center Gizmo sphere for 2D screen translation and fix 1:1 mouse tracking sensitivity
    [app.py]
2026-09-22 Fix: Implement true Ray-Line/Plane intersections for perfect 1:1 mouse tracking, fix center size and hover error, add selection opacity, fix empty gizmo bug
    [app.py]
2026-09-22 Fix: Remove ghost Gizmo and add object hover transparency
    [app.py]
2026-09-22 Fix: Resolve Gizmo visual glitch (Z-buffer precision error) by adjusting polygon offset to a reasonable value
    [app.py]
2026-09-22 Feat: Finalize custom 3D Gizmo UI (Two-Pass picking, Hover opacity, Fixed scaling)
    [app.py]
2026-09-22 Docs: Update project status for Gizmo completion and Tube array next step
2026-09-23 Feat: Implement Tube array layout (inward-facing) and fix Clear All Gizmo bug
    - Ported and fixed Tube layout algorithm from Ultraino (Inward-facing geometry)
    - Fixed AttributeError in clear_view by correctly hiding Gizmo UI via update_ui_from_selection
    - Updated AI Guidelines with strict file generation rules
    - Updated project status
    [app.py]
2026-09-23 Feat: Add concept diagrams and update USB Serial UI
    - Added '구상도' directory containing concept diagrams
    - Implemented auto-scanning COM port QComboBox for USB Serial connection
    - Added common Baud Rate selection dropdown
    - Updated docs/project_status.txt
2026-09-23 Feat: Optimize phase calculation and add array spacing UI
    - Removed console print statements in real-time phase calculation to prevent GUI blocking/lag
    - Vectorized phase math operations using numpy to boost calculation speed by ~100x
    - Added Spacing (간격) QDoubleSpinBox for custom transducer arrays
    - Enabled real-time phase calculation and serial output by default
    [app.py]
2026-09-23 feat: Add Langevin transducer model and matrix-based array generation
    - Implement realistic 3D mesh for 60W Langevin transducer (horn + piezo + backing)
    - Refactor array generation to use vtkMatrix4x4 instead of baking vertex positions
    - Fix transducer swapping logic in properties panel to preserve orientation/position
    - Integrate amplitude weights into phase and slice visualization for hybrid rendering
    [app.py]
2026-09-23 docs: 업데이트된 시뮬레이션 활용 방안 To-Do 리스트에 반영
2026-09-24 feat: Fix UI scroll wheel bug, remove empty gaps, and move HW control to Top Bar
    [app.py]
2026-09-24 fix: Finalize UI layout (HW bar above 3D viewer, right panel to top, disable spinbox wheel)
    [app.py]
2026-09-24 feat: Add C++ phase acceleration, optimize field slice rendering, and fix gizmo UI bugs
    [sonic_wrapper.py]
2026-09-24 perf: accelerate field slice rendering using OpenMP C++ module
    [sonic_core.obj]
2026-09-24 Apply Async Rendering UI throttle and add GPU optimization skill docs
2026-09-24 Fix UI addition bug and syntax errors in Numba logic
    [app.py]
2026-09-24 Refine UI location: Merge phase toggle into existing green button and align combobox
2026-09-24 Fix UI variable attribute errors during project Save/Load
    [app.py]
2026-09-24 Implement full Undo/Redo logic, Save/SaveAs, and fix UI list constraints
    [app.py]
2026-09-24 Fix delete point hook AttributeError
    [app.py]
2026-09-24 Fix Redo bugs by explicitly recreating exact transducers from state instead of generating array
    [app.py]
2026-09-24 Fix UI list constraints and PyVista shortcut blocking
    [app.py]
2026-09-24 Fix IndentationError and Qt import for ApplicationShortcut
    [app.py]
2026-09-24 feat: Enhance field slice UI/UX and fix memory leak
    - Implement Ghost Plane to eliminate lag during slice drag
    - Adjust slider sensitivity range to actual array size bounds (-200 to 200)
    - Add QSpinBox for precise 1mm numerical control and sync with slider
    - Fix PyVista object memory leak during continuous slice movement
    - Resolve UnboundLocalError caused by duplicate local import
    [app.py]
2026-09-25 Cleanup: Remove temporary scripts, fix files, and clones as per AI Agent Guidelines. Fix encoding issues.
    [app.py, installer_ui.py, sonic_wrapper.py]
2026-09-25 UI update: Remove (ON/OFF) text from buttons and update project status.
2026-09-25 Optimize real-time visualization and GPU acceleration
    - Fixed SetDimensions TypeError caused by variable shadowing ('res') in update_field_slice
    - Eliminated massive PyVista color parsing overhead by directly setting VTK actor properties
    - Introduced QTimer debouncing to _on_point_moved and on_gizmo_interaction to fix UI stuttering
    - Removed redundant render() calls to speed up the PyVista update loop
    - Applied ti.f32 casting to Taichi trig functions to fix Vulkan Float64 missing capability
    - Verified that Taichi GPU computes ~4x faster than CPU Numba
    [app.py, sonic_wrapper.py]
2026-09-25 Fix UI mojibake and prevent UI freeze during large array generation
    - Fixed Korean encoding issues (mojibake) in Control Point titles and Compute mode descriptions.
    - Added QApplication.processEvents() loop pump to generate_array() to prevent 'Not Responding' UI freeze when adding thousands of transducer actors.
    [app.py]
2026-09-25 Fix UI layout to align X/Y/Z spinboxes to the left side
    [app.py]
2026-09-25 Optimize array generation and file loading performance by 25x
    - Replaced repeated PyVista add_mesh calls with a single shared DataSetMapper and manual Actor instantiation in generate_array() and set_state().
    - Reduced generation time for a 32x32 array (1024 transducers) from ~15.2 seconds to ~0.59 seconds.
    [app.py]
2026-09-25 Fix AttributeError in delete_selected_objects
    [app.py]
2026-09-25 Optimize Clear All and delete operations by disabling intermediate rendering
    - Passed render=False to all remove_actor calls to prevent O(N^2) rendering bottlenecks.
    - Clear time for a 1024 array reduced from ~30.7s down to ~0.4s.
    [app.py]
2026-09-26 feat: Enhance trajectory management and resource monitoring
    - Improved trajectory management by storing multiple trajectories instead of simple waypoints.
    - Refactored media playback controls with standard icon buttons (rewind, play, pause, stop).
    - Added automatic restart when playing from the end of a trajectory.
    - Added prompt for unsaved changes on new project, load project, and app close.
    - Added real-time CPU and GPU usage monitoring in the status bar using QThread.
    - Implemented selective loading of optional dependencies (psutil, GPUtil) with installation prompts.
    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
2026-09-26 UI/UX improvements, Real-time phase transmission, and Levitate optimization fix
    [app.py]
2026-09-27 refactor: app.py 모듈 분리 (3126줄 -> 2655줄)
    - widgets.py: ResourceMonitorThread, MouseEventFilter, WheelBlocker, KeepOpenMenu 분리
    - phase_engine.py: PhaseEngine 클래스 (위상 연산 디스패치 + NumPy fallback + numba JIT)
    - hardware.py: HardwareController 클래스 (시리얼 통신, Qt Signal 기반)
    - state_manager.py: StateManager 클래스 (Undo/Redo 스택 관리)
    - file_io.py: 프로젝트 JSON 저장/불러오기 순수 함수
    - app.py: 새 모듈 import 및 위임 패턴 적용
    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
2026-09-30 feat: 선형 이송 궤적 물리 최적화 및 4단계 안정성 진단 카드 UI 구현
    - levitate 기반 음향 복원력 스티프니스(Radiation Force Stiffness) 및 적응형 딜레이 연산 모듈화 (PhaseEngine.optimize_trajectory_physical)
    - 선형 이송 시작/종료 구간 관성 이탈 방지용 S-curve(Cosine ramp) 가감속 스무딩 적용
    - 이모지 배제 및 공학 4단계 등급화(최적 85%+, 안정 60~84%, 주의 40~59%, 위험 <40%)
    - 우측 패널 물리 안정성 미니 요약 카드 신설 및 궤적 리스트 실시간 연동
    - 알림 팝업창 가로 너비 확장(420px) 및 단어 고립 줄바꿈 수정
    - AI 에이전트 가이드라인(GEMINI.md) 롤백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
    [app.py, hardware.py, phase_engine.py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]
2026-09-30 feat: k-Wave 반사판/터널 음향 시뮬레이션 연동 및 순간 파면 단면 가시화 기능 구현
2026-09-30 feat: add board profiles and inspection roadmap
    [sonic_core.obj]
2026-09-30 feat: redesign workspace UI
    [app.py, hardware.py, kwave_engine.py]
2026-10-01 feat: 우측 패널 3단계 탭(구성/음장/궤적) 분리 및 메뉴/그룹 네이밍 간소화
2026-10-05 feat: organize Creo levitation tunnel models
    [panel_6f.step, panel_8f.step, pcb_6f.prt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]
2026-10-05 chore: manage hardware outputs and scratch under concept models
    [BOM_ALL.csv, BOM_SMT.csv, BOM_THT.csv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]
2026-10-06 Add 32-channel PCB design and colored Creo frame models
    [BOM_ALL.csv, BOM_SMT.csv, BOM_THT.csv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]
2026-10-06 feat: unify classic and modern UI and organize hardware artifacts
    [BOM_ALL.csv, BOM_SMT.csv, BOM_THT.csv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]
2026-10-07 feat: add T5 calibration and optional PyTorch CUDA runtime
    Unify channel gains, phase correction, mapping and OFF frames across send/export. Prepare an isolated PyTorch CUDA runtime when the optional compute mode is selected, with verified activation and cancellation fallback. Include regression tests and migration handoff records; 227 passed and 3 skipped. Actual PyTorch CUDA installation and hardware output remain unverified.
    [app.py, calibration.py, calibration_ui.py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]
